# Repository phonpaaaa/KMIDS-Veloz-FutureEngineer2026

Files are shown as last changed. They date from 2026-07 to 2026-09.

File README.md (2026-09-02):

<div align="center">

# KMIDS Veloz
## 2026 WRO – Future Engineers
**Official Engineering Documentation**

> Designing, building, and continuously improving an autonomous vehicle for the World Robot Olympiad Future Engineers challenge.

<!-- IMAGE: Robot overview photo (final robot, 3/4 angle, clean background) -->
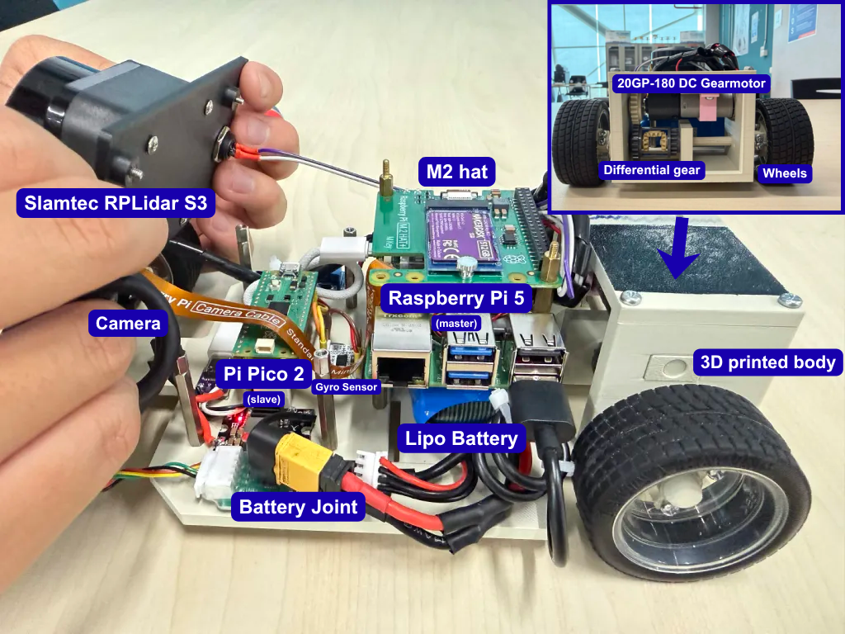
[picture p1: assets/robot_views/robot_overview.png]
Robot overview


</div>

---

## Team Members

<!-- IMAGE: Team photo -->

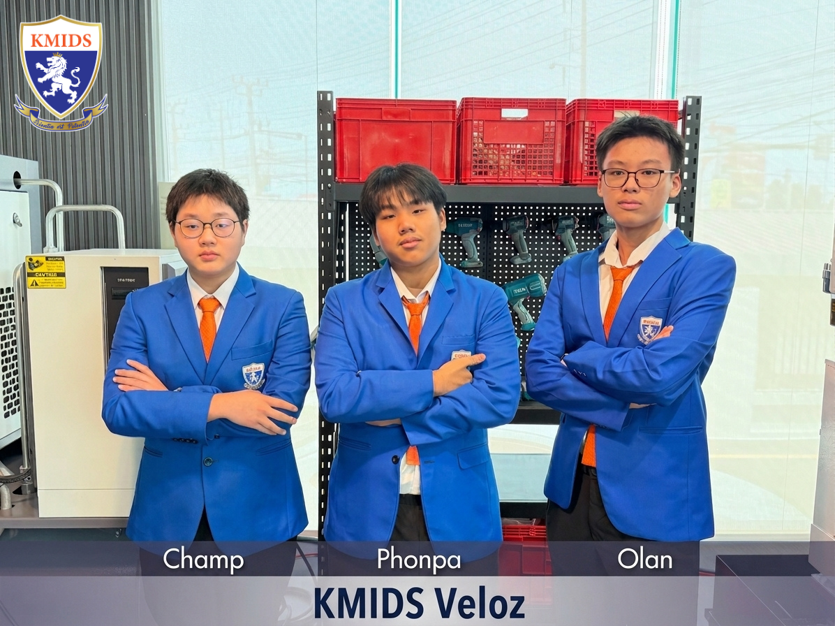
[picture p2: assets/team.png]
Team photo


| Member Name | Chief Responsibilities | Key Activities |
|---|---|---|
| **Sahas Ninvatchararang (Phonpa)** | Robotics, Electronics & Software | Physical robot construction, electronics integration, sensor and motor implementation, programming, control-system development, and testing |
| **Olan Sinsuriya (Olan)** | CAD, Mechanical Design & Engineering | Chassis and component CAD, mechanical design, assembly development, design iterations, and fabrication support |
| **Phisit Chuthomsuwan (Champ)** | Documentation, Research & Project Coordination | Technical documentation, research, recording development decisions, organizing project information, and supporting testing and validation |

During the development process, we divided the work while also supporting each other, meaning one person may focus on designing CAD models, while helping debug the initial calibration code. This was to ensure proper coordination and teamwork.

**KMIDS Veloz** is a team of students exploring autonomous driving through mechanical design, embedded systems, computer vision, and control theory. Over the course of the WRO Future Engineers 2026 season, our work has covered hardware selection, CAD design, electronics integration, and the software architecture running on our two onboard boards (Raspberry Pi 5, Raspberry Pico), along with the testing and iteration that shaped each of those decisions. This document outlines our entire process from start to finish, including engineering decisions, hurdles, and the eventual solutions we found after rigorous trials.

---
## Table of Contents

1. [Overview](#1-overview)
   - [1.1 About the Project](#11-about-the-project)
   - [1.2 Robot Images](#12-robot-images)
   - [1.3 Performance Video](#13-performance-video)
2. [Mobility Management](#2-mobility-management)
   - [2.1 Drive System](#21-drive-system)
   - [2.2 Steering](#22-steering)
   - [2.3 Chassis Design](#23-chassis-design)
3. [Power and Sense Management](#3-power-and-sense-management)
   - [3.1 Power Source](#31-power-source)
   - [3.2 Sensor and Camera](#32-sensor-and-camera)
   - [3.3 Processing Units](#33-processing-units)
   - [3.4 Circuit Diagram](#34-circuit-diagram)
   - [3.5 Power Consumption](#35-power-consumption)
4. [Software Architecture](#4-software-architecture)
   - [4.1 Code Organization](#41-code-organization)
   - [4.2 Sensing Modules](#42-sensing-modules)
   - [4.3 Reactive Navigation Controller](#43-reactive-navigation-controller)
5. [Obstacle Management](#5-obstacle-management)
   - [5.1 Open Challenge](#51-open-challenge)
   - [5.2 Obstacle Challenge](#52-obstacle-challenge)
   - [5.3 Parallel Parking](#53-parallel-parking)
6. [Systems Thinking and Engineering Decisions](#6-systems-thinking-and-engineering-decisions)
7. [Testing and Results](#7-testing-and-results)
8. [Source Code](#8-source-code)
   - [8.1 API Documentation](#81-api-documentation)
   - [8.2 Code Structure](#82-code-structure)
   - [8.3 Compilation / Upload Instructions](#83-compilation--upload-instructions)
9. [List of Components](#9-list-of-components)
10. [3D Model Files](#10-3d-model-files)
    - [10.1 FreeCAD Files](#101-freecad-files)
    - [10.2 STL Files](#102-stl-files)
    - [10.3 Slicer Files](#103-slicer-files)
11. [Building Instructions](#11-building-instructions)
12. [Development Process and Future Improvements](#12-development-process-and-future-improvements)
    - [12.1 Mechanical and Software Iteration History](#121-mechanical-and-software-iteration-history)
    - [12.2 Planned Improvements](#122-planned-improvements)
13. [License](#13-license)

---

## 1. Overview

### 1.1 About the Project

The WRO Future Engineers category requires a vehicle to complete a driving course fully autonomously. The competition is split into two challenges. In the **Open Challenge**, the robot must complete three laps of an empty track without making contact with any wall. In the **Obstacle Challenge**, the track additionally contains randomly placed obstacle pillars that the robot must pass on the correct side, and the run finishes with a precision parallel-parking maneuver into a bay whose position is not known in advance. In both challenges the driving direction and track layout are randomized before the run starts, and in the Obstacle Challenge the pillar placement is randomized too, so the robot has to work out what it's facing from its own sensors rather than following a pre-programmed path.

Our robot splits its computing across two boards, connected over I²C with the Pi 5 as master and the Pico 2 as slave. A **Raspberry Pi 5** handles perception, LIDAR distance sensing and camera-based pillar detection, and runs the navigation logic that decides steering and speed. A **Raspberry Pi Pico 2** takes those commands and drives the motor and steering servo, reporting back encoder and IMU telemetry. Because the Pico is a pure I²C slave, it only acts on the most recent command written to it and does not initiate communication itself (Section 3.3, Section 6).

Our active control software is a hand-tuned reactive LIDAR controller: it reacts directly to the four LIDAR distance readings around the robot rather than planning a path or holding a fixed heading. An earlier version of the codebase used per-axis heading control with an explicit lap/turn state machine; that module (`open_challenge.cpp`) is documented in full in Section 5.1 and Section 12.1. Camera-based pillar detection (`camera.cpp`) is documented in Section 4.2 and Section 5.2. Sections 4, 5, and 12 note the integration status of each piece.

### 1.2 Robot Images

The six required orientation views, four additional angled shots, and a photo of the internal electronics layout are collected below.

<!-- IMAGES: required six views, using our actual filenames -->
| Front | Rear | Left |
|---|---|---|
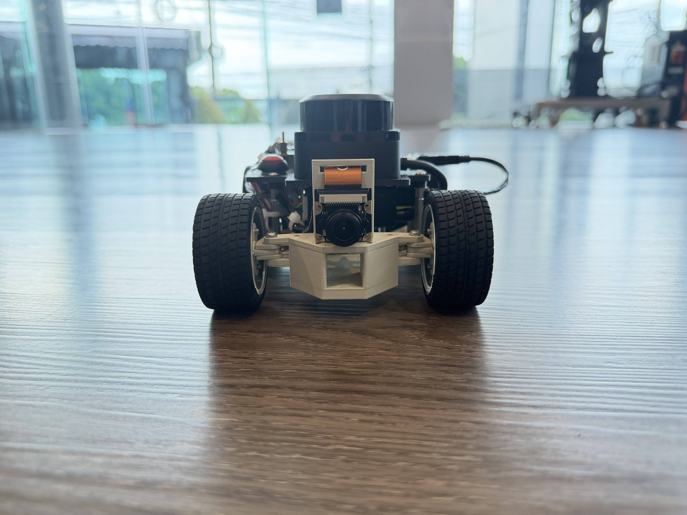
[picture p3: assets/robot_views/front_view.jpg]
Front
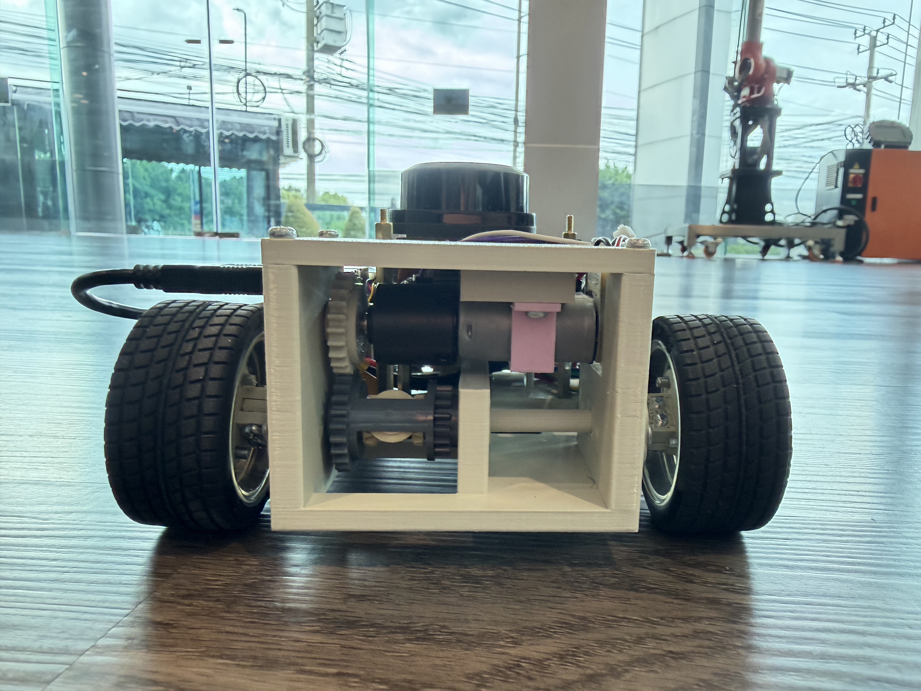
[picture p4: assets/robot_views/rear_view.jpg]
Rear
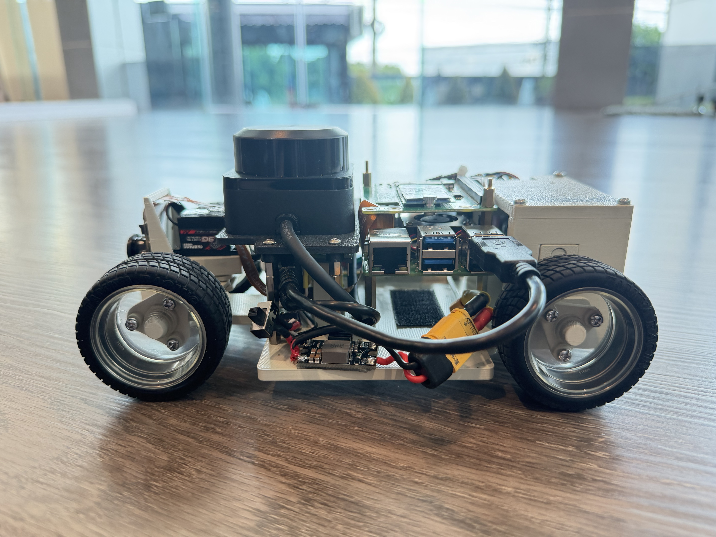
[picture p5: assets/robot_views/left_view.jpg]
Left
|  |  |  |

| Right | Top | Bottom |
|---|---|---|
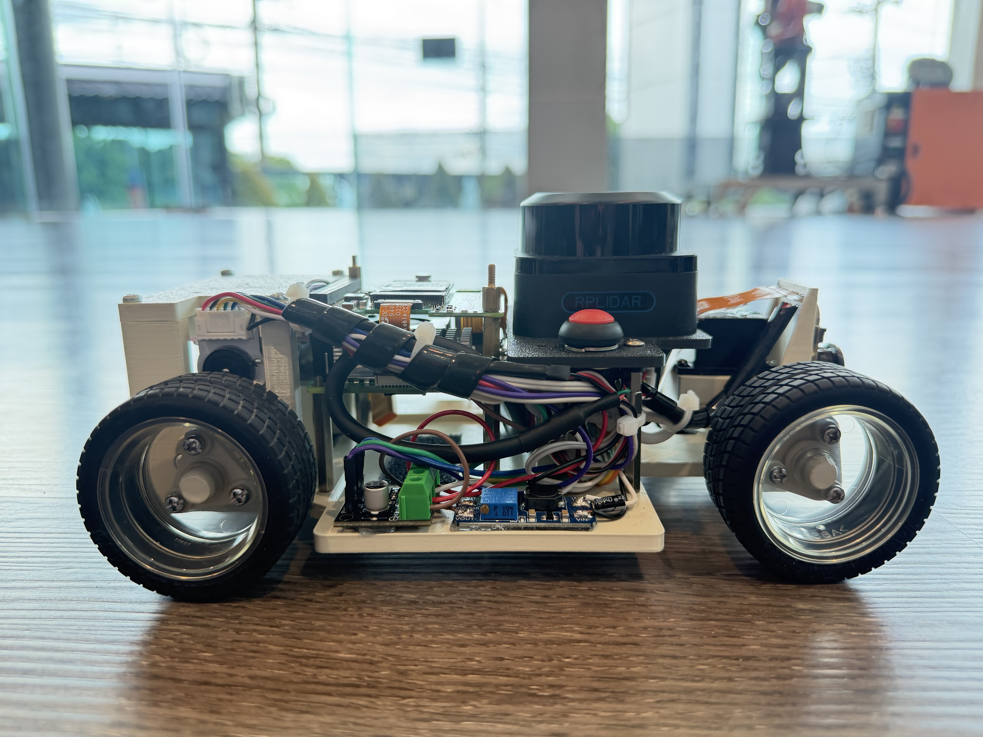
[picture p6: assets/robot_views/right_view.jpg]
Right
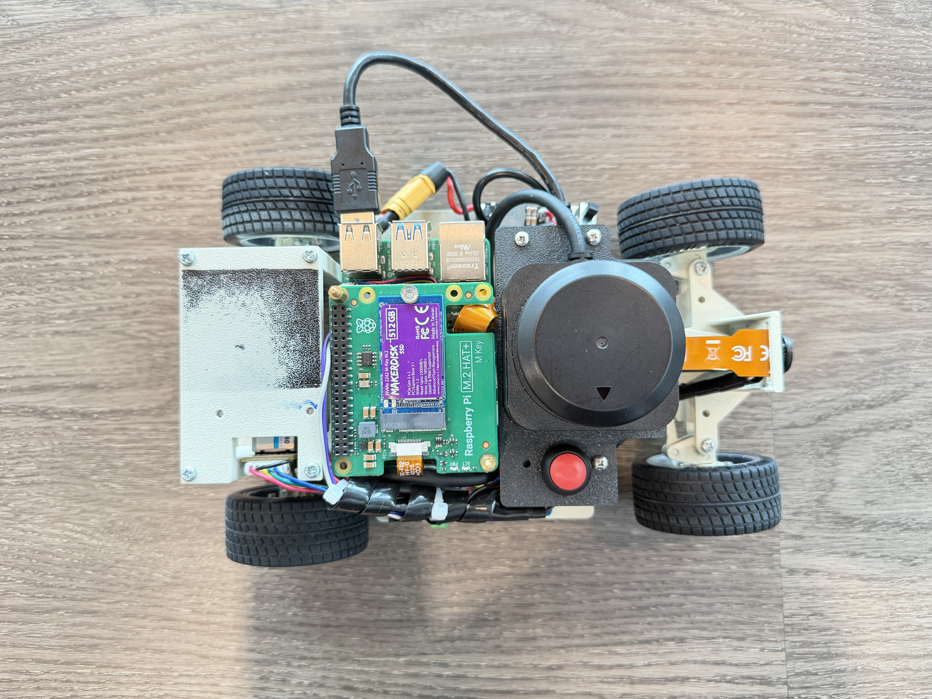
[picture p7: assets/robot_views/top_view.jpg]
Top
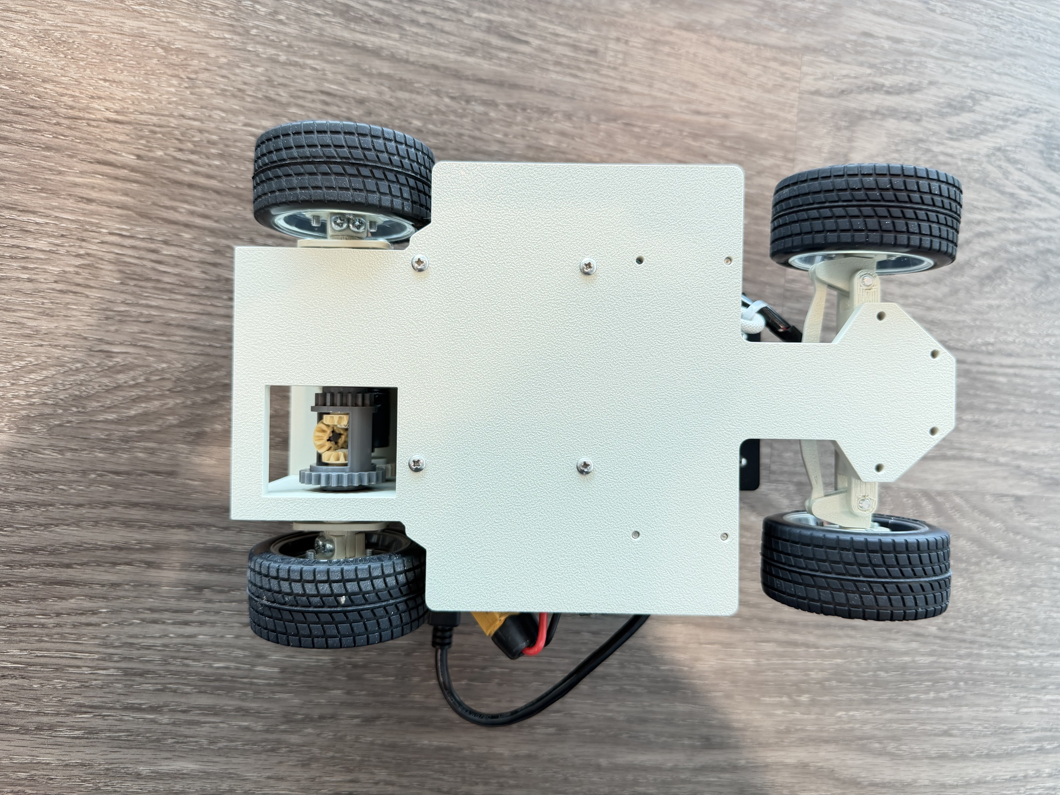
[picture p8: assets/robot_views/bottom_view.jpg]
Bottom
|  |  |  |

**Additional angles:**

| Left side | Left-rear | Right side | Right-rear |
|---|---|---|---|
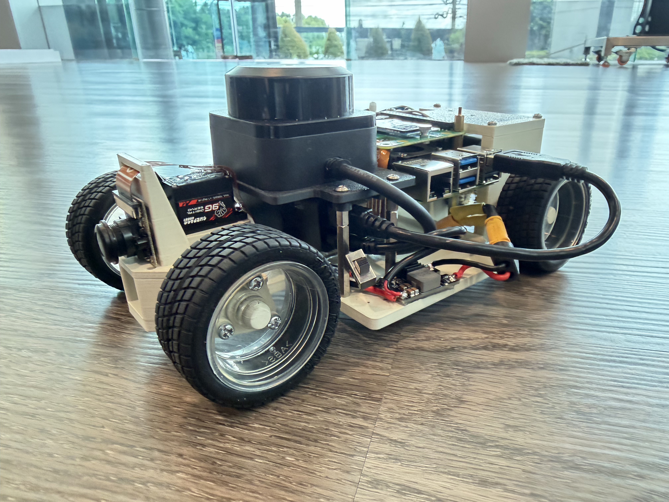
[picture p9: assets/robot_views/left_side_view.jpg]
Left side
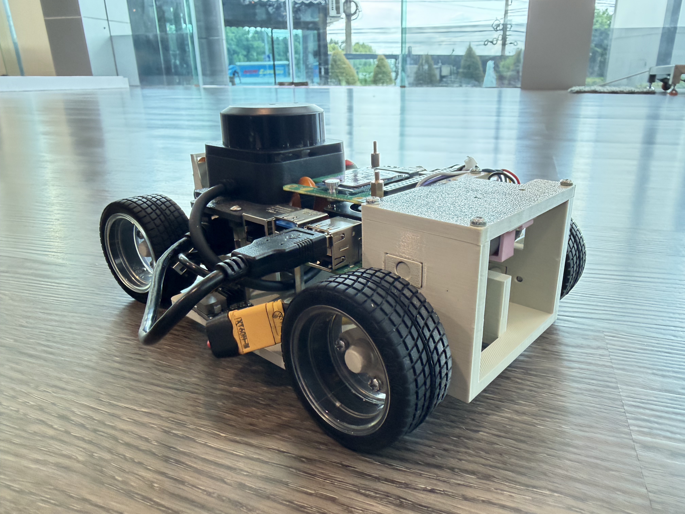
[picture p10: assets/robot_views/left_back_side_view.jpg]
Left rear
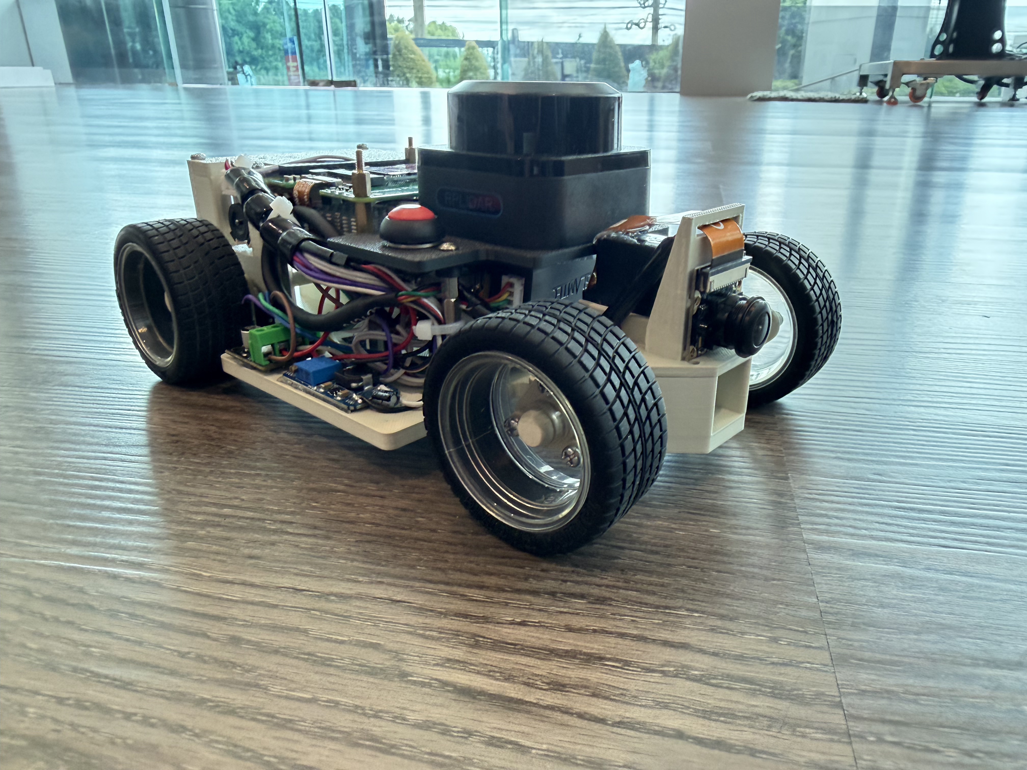
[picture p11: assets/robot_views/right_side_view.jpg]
Right side
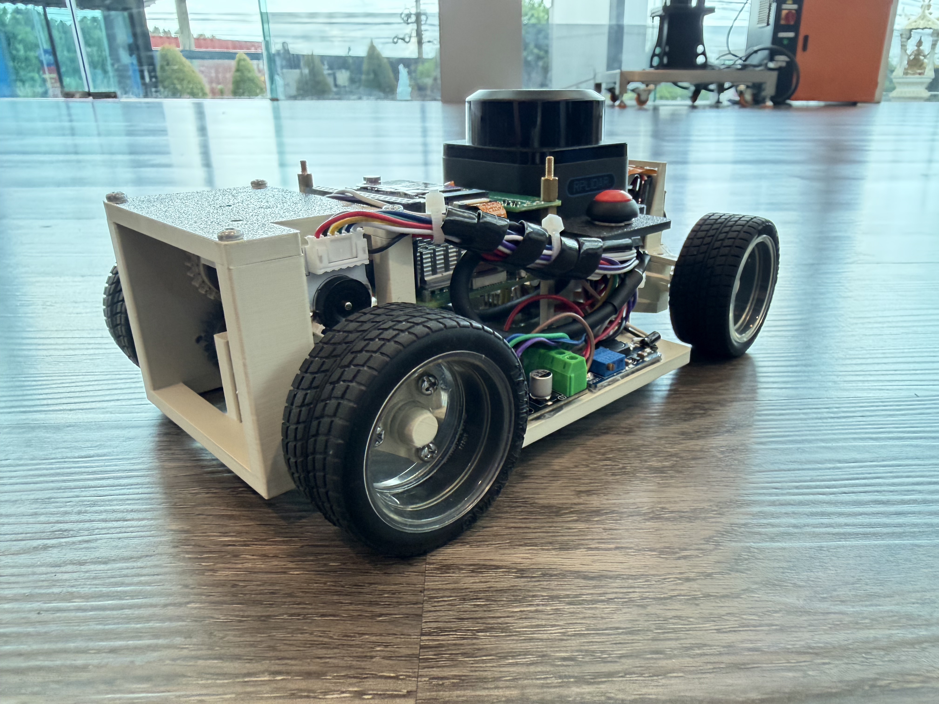
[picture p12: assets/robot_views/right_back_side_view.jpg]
Right rear
|  |  |  |  |

*In the six orientation views and the additional four angled views, the Li-Po battery is not part of the physical assembly, as it was being tested during the photo-taking process.*

**Internal Electronics:**

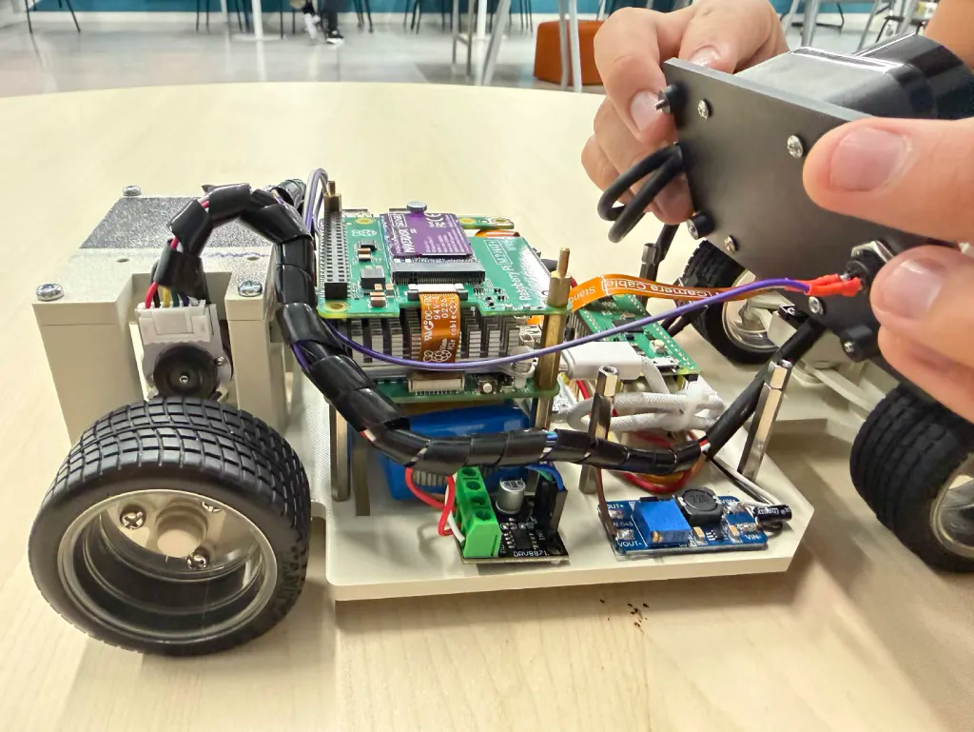
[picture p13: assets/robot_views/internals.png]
Internal electronics


Section 3.2 also includes a labeled top-down sensor placement diagram (`assets/sensor_placement.png`) showing LIDAR, camera, and IMU positions schematically.

### 1.3 Performance Video

**Open Challenge:** *link to be added*

**Obstacle Challenge:** *link to be added*

These two parts show both the Open and Obstacle Challenges respectively.

[Back to Top](#kmids-veloz)

---

## 2. Mobility Management

This section covers how the robot moves: what drives the rear wheels, how the front wheels are steered, and how the chassis is built to hold both systems together.

- **Drive system:** a single 20GP-180 DC gearmotor with an integrated encoder drives the rear wheels through a printed gear.
- **Steering:** the front wheels use Ackermann-geometry steering, actuated by a Surpass Hobby S0009M servo through a printed T-bone/transfer-linkage assembly.

### 2.1 Drive System

The robot uses a single **20GP-180 DC gearmotor with an integrated quadrature encoder** to drive the rear wheels. Power is transferred from the motor through a printed gear system (`MotorGear.FCStd`), while encoder feedback is wired back to the Raspberry Pi Pico 2 so wheel rotation can be measured directly instead of assumed.

<!-- IMAGE: 20GP-180 motor photo -->
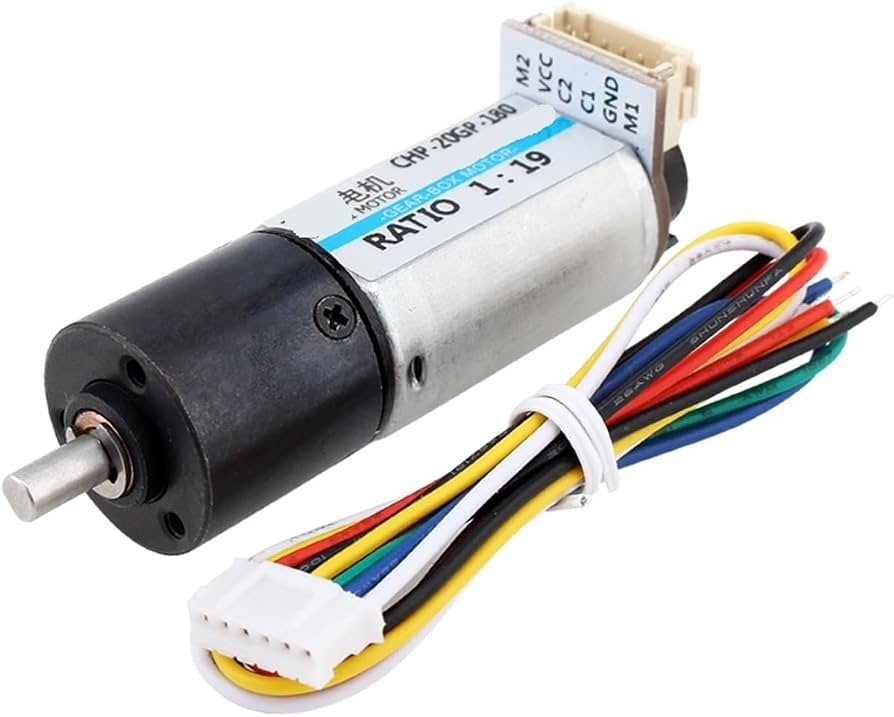
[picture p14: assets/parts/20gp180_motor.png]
20GP-180 DC gearmotor


#### Motor: 20GP-180 DC Gearmotor

The 20GP-180 is the vehicle's only drive motor. It's mounted at the rear of the chassis and drives the rear axle through the printed drivetrain components described below.

**Specifications**

| Specification | Value | Source (evidence) |
|---|---:|---|
| Motor | 20GP-180 DC gearmotor | Manufacturer / vendor documentation |
| Rated voltage | 6–12 V | Manufacturer / vendor documentation |
| Operating voltage | 12 V (stepped up from the 5V logic rail) | Our configuration |
| Weight | ~80 g | Vendor specification |
| Gearbox | All-metal planetary | Vendor specification |
| Encoder | Quadrature (AB dual-phase Hall) | Vendor specification / hardware |
| Encoder pulses | 28 pulses/rev | Our firmware |
| Gear ratio | 100:1 | Our configuration / hardware |
| No-load RPM (this ratio) | ~120–150 RPM at 12V | Vendor family curve |
| Stall torque (this ratio) | ~4–6 kgf·cm at 12V | Vendor family curve |

The 20GP-180 family is sold across several gear ratios with no-load speed and stall torque changing accordingly, so the figures above are read from the vendor's general curve for this ratio rather than a bench measurement of our specific unit. It is possible to put the wheel on a bench and logging encoder counts over a fixed time at full duty to get a real number.

**Reason for selection:** the encoder was the deciding factor in choosing this motor over an equivalent plain DC motor. Encoder feedback means wheel rotation can be measured directly rather than assumed from a PWM duty cycle, which matters because a fixed duty cycle does not produce a fixed speed. The motor's actual output changes as battery voltage, load, and friction change over the course of a run. The 20GP-180 also strikes a useful balance of torque, gearing, and physical size for the current chassis: its geared output provides enough mechanical torque to accelerate the vehicle and hold speed on the competition mat, while its dimensions fit within the rear drivetrain without needing an oversized motor mount.

**Encoder and closed-loop speed control:** the motor's quadrature encoder reports rotational feedback to the Pico 2 as part of its telemetry (`encoder_count`, `rpm_x10` in the `PicoTelemetry` struct, see Section 3.4). At 28 pulses/rev through a 100:1 gear ratio, the encoder gives fine-grained resolution on wheel rotation, over 2,800 counts per output-shaft revolution. The Pi 5's navigation controller currently commands speed open-loop as a percentage (Section 4.3); telemetry is read every loop but is not yet closed into a speed loop on the Pi 5 side. We sequenced it this way on purpose. Tuning a speed controller against steering behavior that was still unstable (Section 7) would mean chasing a moving target, so getting steering solid came first. Closing the loop on `rpm_x10` to hold a literal target wheel speed is next.

**Motor gear:** power from the motor is transferred through a printed motor gear (`MotorGear.FCStd`).

<!-- IMAGE: Motor gear -->
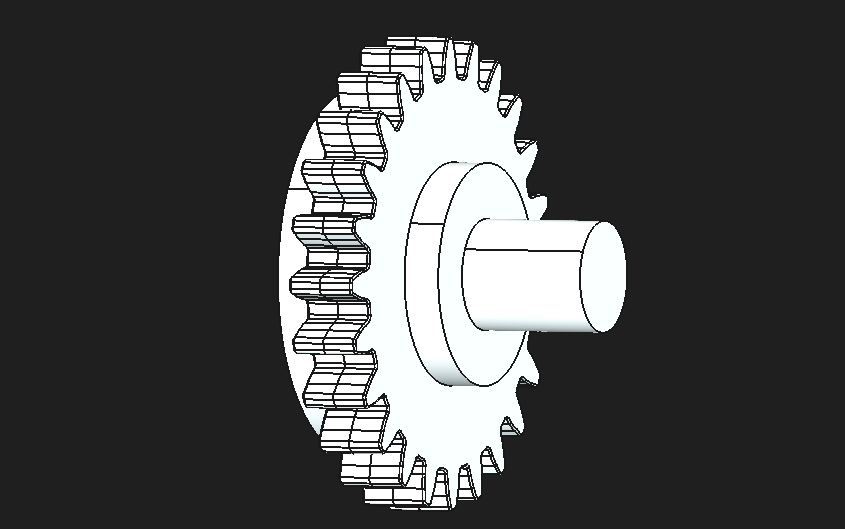
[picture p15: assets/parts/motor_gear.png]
Motor gear


The gear is a separate printed component rather than being integrated directly into the chassis, which makes the drivetrain easier to modify if the motor, gear ratio, or wheel configuration changes during development. Our CAD parts list also includes `LegoBevelGear.FCStd` and `LegoDifferentialGear.FCStd`. We used off-the-shelf LEGO Technic gear elements paired with a `16GA.FCStd` axle rod inside the rear axle assembly rather than designing custom bevel/differential gearing from scratch, which saved print-and-fit iteration on a part that's easy to get wrong and cheap to buy correct.

**Motor mounting:** the motor is mounted using a printed motor holder and a detachable motor plate.

<!-- IMAGE: Motor holder -->
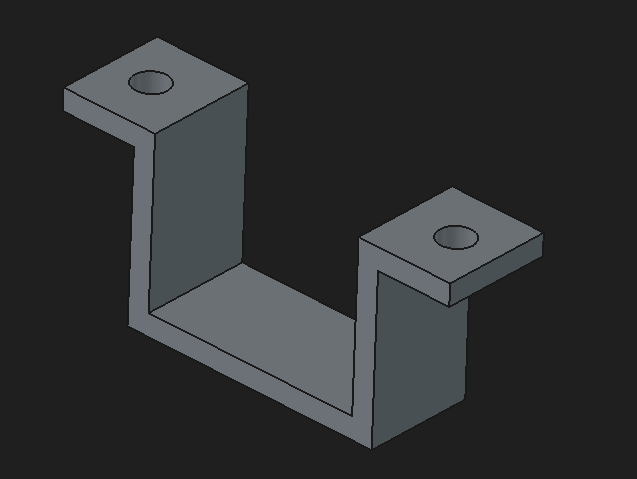
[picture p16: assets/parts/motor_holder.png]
Motor holder


**Motor plate:** the detachable mounting plate that secures the motor holder to the chassis, allowing the motor to be removed or replaced without reprinting the entire chassis.

<!-- IMAGE: Motor plate -->
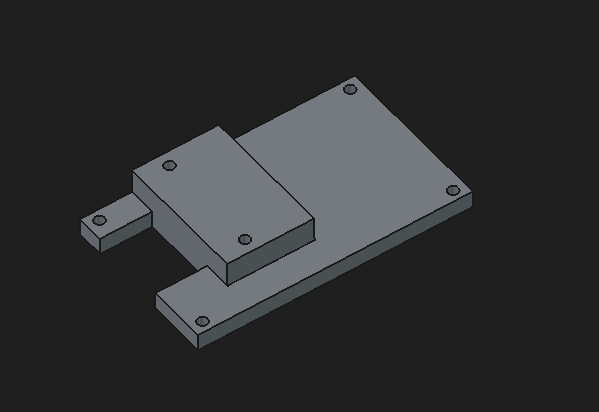
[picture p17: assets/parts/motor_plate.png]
Motor plate


Relevant CAD files: `MotorHolder.FCStd`, `MotorPlate.FCStd`, `MotorGear.FCStd`.

The motor plate is deliberately kept as a separate piece rather than being printed as part of the main chassis. This means the motor can be removed or replaced without requiring the entire chassis to be reprinted, and leaves room for future drivetrain changes. If testing shows a different motor or gear ratio would give better acceleration or top speed, the mounting assembly can be redesigned independently of the main chassis.

**Electrical connection:** the motor is driven by the Raspberry Pi Pico 2 through motor-driver circuitry. The Pico provides PWM/direction control signals rather than powering the motor directly. Encoder signals are wired back to the Pico's encoder inputs, giving it continuous rotation feedback. This keeps the high-current motor path physically separate from the low-voltage control signals:

```text
Raspberry Pi Pico 2
       │  PWM / direction
       ▼
  Motor Driver
       │  motor power
       ▼
  20GP-180 Motor
       │  mechanical output
       ▼
 Rear drivetrain
       │  encoder feedback
       ▼
Raspberry Pi Pico 2
```

**Mechanical integration:** the motor and its mounting components sit at the rear of the chassis so the drivetrain stays contained while leaving the rest of the vehicle available for steering and electronics. Because the motor plate is detachable, the motor can be accessed for maintenance without disassembling the whole chassis.

**Design considerations: torque, speed and integration trade-off:** the main trade-off with the current motor is between speed, torque, size, and how easily it integrates with the rest of the vehicle. At a 100:1 ratio the 20GP-180 gives up top speed in exchange for torque and low-speed control resolution. We picked this ratio deliberately over a lower one (e.g. 30:1–50:1) because the Obstacle Challenge rewards controlled, repeatable maneuvering around pillars and into the parking bay more than raw straight-line speed, and our reactive controller (Section 4.3) already caps speed to 70–73% duty in normal driving. The current ceiling on lap time is cornering confidence, which is a steering/tuning problem (Section 7), not a motor problem. A shorter gear ratio would raise top speed but reduce the torque margin available for accelerating out of corners, and would need a re-tune of the whole reactive controller's speed table.

**Current drivetrain configuration**

| Component | Function |
|---|---|
| 20GP-180 DC gearmotor | Provides drive power |
| Quadrature encoder | Measures rotational movement |
| `MotorGear.FCStd` | Transfers motor output |
| `LegoBevelGear.FCStd` / `LegoDifferentialGear.FCStd` | Off-the-shelf rear axle gearing |
| `16GA.FCStd` | Rear axle rod |
| `MotorHolder.FCStd` | Secures the motor |
| `MotorPlate.FCStd` | Provides detachable motor mounting |
| Motor driver | Controls motor power |
| Raspberry Pi Pico 2 | Sends motor commands, reads encoder telemetry |
| `BackWheelAxleLeft.FCStd` / `BackWheelAxleRight.FCStd` | Transfers rotational movement to wheels |
| `BackWheelConnector.FCStd` | Connects wheels to drivetrain |
| `BackWheelStopper.FCStd` | Secures wheels in place |
| Rear wheels (`Wheel.FCStd`) | Convert motor output into vehicle movement |

#### Motor Selection: Compared Side by Side

Before settling on the 20GP-180, we compared it directly against the two other drive options on the table: a plain (non-encoded) DC gearmotor of similar size, and a continuous-rotation servo, which some teams use to avoid a separate motor driver.

| Option | Speed control | Feedback | Torque | Why we did / didn't pick it |
|---|---|---|---|---|
| 20GP-180 + encoder (chosen) | PWM, closed-loop-ready | Quadrature encoder, 2,800+ counts/rev | 4–6 kgf·cm @12V (100:1) | Only option where wheel speed is measured, not assumed. Directly enables the closed-loop speed control planned in Section 2.1. |
| Plain DC gearmotor (no encoder) | PWM, open-loop only | None | Similar, ratio-dependent | Cheaper and simpler, but duty cycle does not track real speed as battery voltage sags or friction changes. Rejected: no path to closed-loop control without a hardware change later. |
| Continuous-rotation servo | PWM (servo protocol) | None (most hobby-grade units) | Lower, geared for low current draw | Simplifies wiring (no separate motor driver), but has less torque margin for cornering acceleration and no rotation feedback. Rejected: torque and feedback both mattered more than wiring simplicity here. |

### 2.2 Steering

<!-- IMAGE: Ackermann steering geometry reference diagram -->
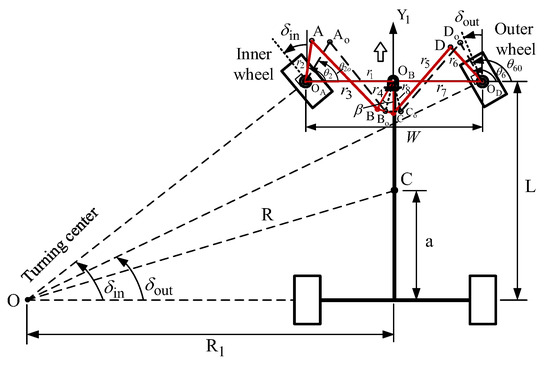
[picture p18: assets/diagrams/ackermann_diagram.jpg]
Ackermann steering geometry


Our steering geometry (`FreeCAD-Files/Models/SteeringAckermannModel.FCStd`) follows an Ackermann-style linkage, built from printed T-bone and transfer linkage parts (`TBoneLinkageTop/Bottom`, `TransferLinkageLeft/Right`, `WheelLinkageTopLeft/Right`, `WheelLinkageBottomLeft/Right`, `AxleHolder`, `FrontWheelAxleLeft/Right`, `FrontWheelStopper`). Ackermann geometry angles the inner and outer front wheels differently during a turn so that both wheels roll instead of scrubbing sideways against the mat. This matters most in the Obstacle Challenge, where the robot needs a tight and repeatable turning radius to get around pillars and into the parking bay without excess slip changing its actual path from run to run.

The diagram above is a general technical reference for the Ackermann geometry principle, not a rendering of our specific linkage. See the FreeCAD file and the CAD assembly image in Section 2.3 for our actual implementation.

#### Servo: Surpass Hobby S0009M (9g digital)

<!-- IMAGE: Servo photo -->
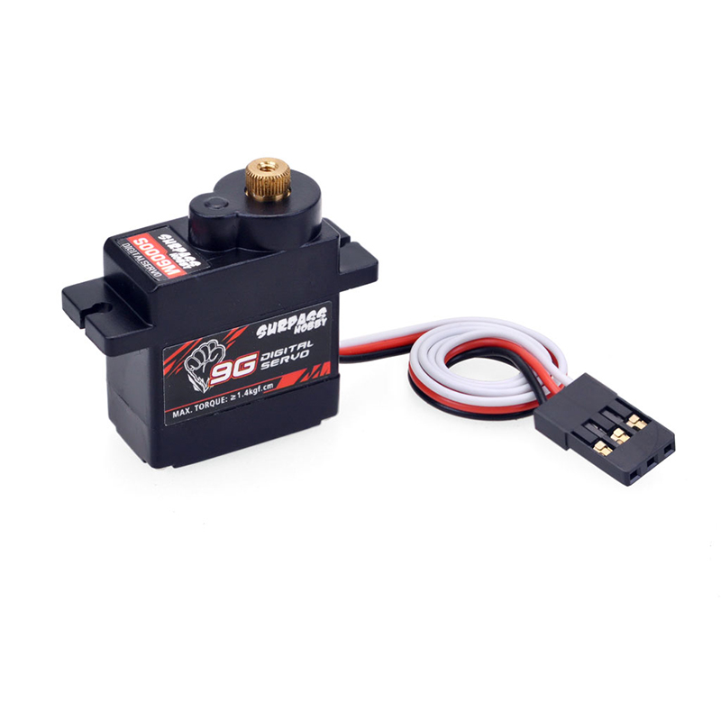
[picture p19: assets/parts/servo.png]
Surpass Hobby S0009M servo


**Specifications**

| Specification | Value | Source |
|---|---|---|
| Rated torque | 1.1 kgf·cm | Vendor specification |
| Speed | 0.15 sec/60° | Vendor specification |
| Voltage | 5V | Vendor specification / hardware |
| Gearing | Metal | Vendor specification / hardware |
| Type | Digital | Vendor specification |

The listed specifications are based on the vendor specification and cross-checked against a second product listing.

**Reason for selection:** the servo's small size and standard PWM interface make it easy to drive directly from the Pico 2, without needing a separate driver board. It also provides enough torque to steer the front wheels responsively at this vehicle's weight, while being small and light enough to mount directly to the front plate without any extra bracketry.

#### Servo Selection: Compared Side by Side

| Option | Torque | Speed | Resolution | Why we did / didn't pick it | Source |
|---|---|---|---|---|---|
| S0009M digital (chosen) | 1.1 kgf·cm | 0.15s/60° | Standard digital PWM | Enough torque for this vehicle's weight, small enough to mount on the front plate directly, and drives natively from the Pico's PWM, no extra driver board needed. | Vendor specification |
| Generic analog 9g servo | ~1.0 kgf·cm | ~0.12–0.20s/60° | Coarser, more deadband | Cheaper, but analog servos have a wider deadband, which showed up as looser centering during early bench tests. Rejected for the tighter steering precision parking demands. | Generic category; not a specific product |
| Larger metal-gear servo (e.g. MG90S-class or bigger) | 2–3 kgf·cm | Similar or slower | Similar digital resolution | More torque margin, but heavier and physically larger than the front plate mount was designed for. Rejected for this chassis revision; noted as the first upgrade path if servo precision becomes a limiting factor (see Design Considerations). | Generic category; not a specific product |

#### Linkages

<!-- IMAGE: T-bone and transfer linkage parts -->
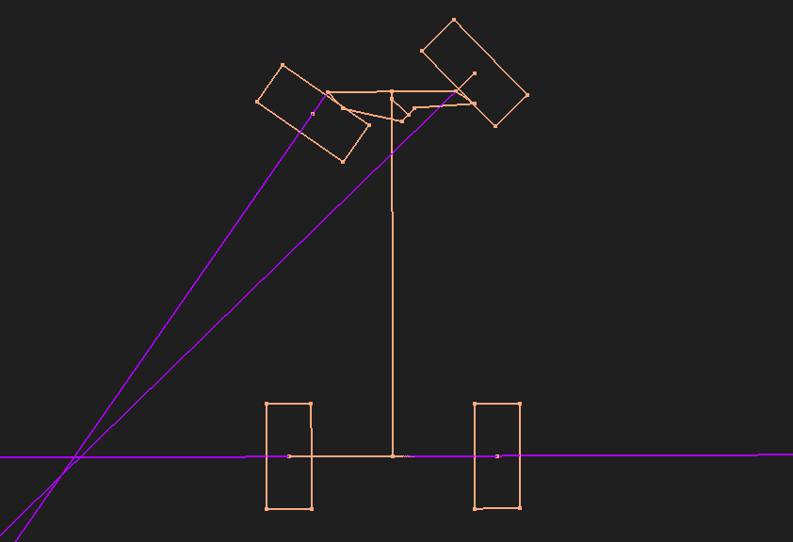
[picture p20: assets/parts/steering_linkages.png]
Steering linkage parts


The T-bone linkage connects the servo horn to the two transfer linkages, which in turn connect to the wheel linkages at each front wheel. Splitting the linkage into separate printed parts (rather than one solid arm) lets us adjust pivot points and re-print a single part if a specific linkage geometry needs revising, instead of reprinting the whole steering assembly.

#### Servo Control

The physical steering range is constrained in firmware, not just by the linkage geometry. Our active navigation controller (`navigation.cpp`, Section 4.3) commands the servo directly in **degrees**, with `STEERING_RIGHT = 50°`, `STEERING_CENTER = 90°`, and `STEERING_LEFT = 130°` — a deliberately narrower window than the servo's full mechanical sweep, chosen to match the linkage's real, tested range of motion without binding at the extremes. The `open_challenge.cpp` module (Section 5.1) uses a slightly narrower range (`60°`–`90°`–`120°`) from an earlier tuning pass. The steering ranges will be reconciled before `open_challenge.cpp` is reactivated.

#### Mounting

<!-- IMAGE: Servo mounting on front plate -->
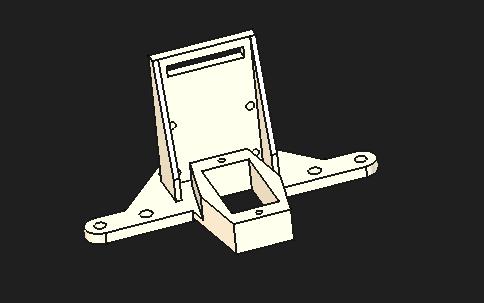
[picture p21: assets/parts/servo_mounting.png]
Servo mounting


The servo is screwed directly into a platform plate at the front of the chassis, connected to the steering mechanism described above.

#### Design Considerations

The S0009M is adequate for the current vehicle weight and turning demands, but a higher-resolution digital servo with a narrower deadband would allow finer steering adjustments, particularly useful for the tight maneuvering required during parking. Driving the servo through a dedicated PWM driver (e.g. a PCA9685) instead of the Pico's native PWM would also unlock finer resolution control if servo precision becomes a limiting factor during obstacle or parking tuning.

Physical steering iterations are validated through the testing results in Section 7.

### 2.3 Chassis Design

The finished chassis body measures 209 mm (long axis) × 130 mm (short axis) × 59 mm (height), measured directly from the FreeCAD model.

| Dimension | Value | Source |
|---|---|---|
| Chassis (L × W × H) | 209 × 130 × 59 mm | Measured from CAD |
| Wheelbase (front-to-rear axle) | 181 mm | Measured from CAD |
| Track width (left-to-right wheel) | 85 mm | Measured from CAD |
| Wheel diameter | 54.7 mm | Measured from CAD |

<!-- IMAGE: Annotated CAD assembly (full robot, labeled: chassis, steering, motor, electronics stack) -->
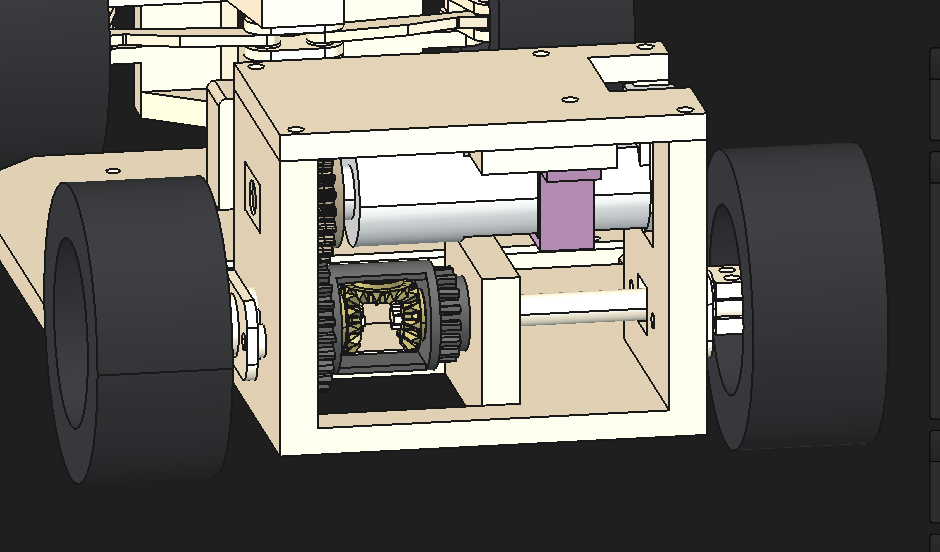
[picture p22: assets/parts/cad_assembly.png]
Annotated CAD assembly


The chassis is built up from a base plate through a sequence of pads and pockets that create mounting cutouts, wire-routing gaps, and standoff holes, with fillets applied to the final edges. This approach does two things at once: it keeps the whole robot well within the WRO 300×200×300mm size limit with margin to spare, and it leaves room to reposition the electronics stack later without having to redesign the body from scratch.

**Design considerations:** the chassis was built with modularity as a priority over minimizing part count. The motor plate, steering front plate, and LIDAR mount are all separate detachable pieces rather than a single printed body, specifically so a subsystem redesign doesn't force a full chassis reprint. A `FrontCover.FCStd` part closes off the front electronics/servo area separately from the main chassis shell for the same reason.

The CAD files for the servo and LIDAR mount are named `S0009M_Mount.FCStd` and `RPLidarS3_Mount.FCStd`, matching the parts installed on the current robot.

[Back to Top](#kmids-veloz)

---

## 3. Power and Sense Management

### 3.1 Power Source

The system's primary logic rail, which supplies the Raspberry Pi 5, Pico 2, camera, IMU, and LIDAR, runs at **5V**. This rail is fed through a UPS module that reports its state of charge over I²C, using register 0x17, matching the EP-0136 protocol implemented in our check_battery_status.py script. This register assignment is based on the module documentation and was cross-checked against an independent reference. Motor power is handled separately: it is stepped up to 12V, since the 20GP-180 gearmotor is rated above what the 5V logic rail can supply on its own.

To protect the battery from being damaged by over-discharge, a `set_battery_min.py` / `ups_shutdown.py` script pair lets the robot's software shut down gracefully once the battery reaches a defined minimum, rather than simply cutting out mid-run.

**Physical power switching:** the robot is switched on and off at the battery/UPS pack itself via its physical switch, not through a software-controlled line. The Raspberry Pi OS shutdown sequence (`ups_shutdown.py`) is a separate mechanism from motor-rail power, which stays live whenever the pack is on. The only software-side stop mechanism right now is the `emergency_stop` flag in `PicoCommand` being honored by the Pico firmware. There's no relay or MOSFET gating the 12V motor rail independently. A physical, easily reachable kill switch on the battery pack is standard practice at competition regardless of what the software does.

### 3.2 Sensor and Camera

<!-- IMAGE: Sensor placement photo/diagram: top-down or side view showing lidar/camera/IMU mounting points -->
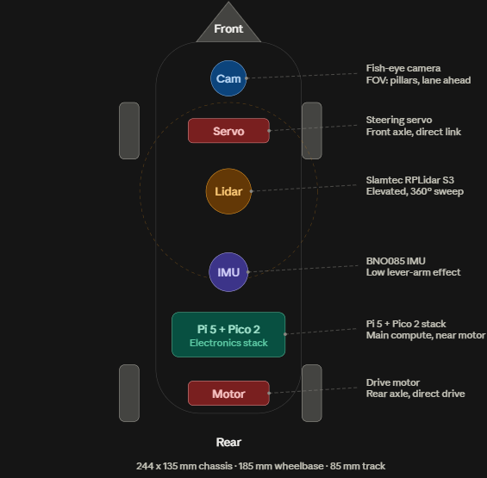
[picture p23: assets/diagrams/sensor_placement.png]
Sensor placement


Each sensor's mounting position was chosen for a specific reason tied to what it needs to see or measure, rather than wherever happened to have free space on the chassis.

| Sensor | Placement | Why there |
|---|---|---|
| Slamtec RPLidar S3 | Front, elevated above the camera/servo stack on a standoff-mounted plate | 360° unobstructed view needs it clear of the chassis body and steering linkage below it |
| Fish-eye camera | Front plate, forward-facing | Needs a forward view of pillars and lane lines ahead of the robot; front-mounting keeps its field of view unobstructed by the chassis |
| BNO085 IMU | Center of chassis, near the Pico 2 | Mounting near the physical center of rotation reduces the lever-arm effect of vibration and centripetal acceleration during turns, which otherwise pollutes the accelerometer/gyro reading |

**Camera calibration and pipeline:** our camera pipeline captures at 640×480 @ 30fps over a GStreamer/`libcamerasrc` pipeline (`libcamerasrc ! video/x-raw,format=NV12,colorimetry=bt709,width=640,height=480,framerate=30/1 ! queue ! videoconvert ! video/x-raw,format=BGR ! appsink drop=true max-buffers=1 sync=false`). The `drop=true max-buffers=1 sync=false` appsink configuration always hands the processing loop the newest available frame and discards anything older, rather than letting frames queue up if a loop iteration runs slow. For a reactive controller, a stale frame is worse than a dropped one. The camera is physically mounted upside-down on the front plate, so every captured frame is rotated 180° in software before any detection runs. Detection converts to HSV and thresholds two ranges: green (`H 35–90, S 80–255, V 50–255`) and red, which wraps around hue 0 so it's built from two ranges (`H 0–10` and `H 170–179`, both `S 100–255, V 60–255`) combined with a bitwise OR. Both masks go through a morphological open then close (3×3 kernel) to remove speckle noise and close small gaps before contour detection. Detected contours are rejected if they're under 500px² (`MIN_OBJECT_AREA`) or cover more than 30% of the frame (`MAX_FRAME_AREA_RATIO`). A further shape filter requires `height > width * 1.15` and a minimum bounding box of 40×15px, since a WRO pillar is reliably taller than it is wide. Exposure and white balance are locked for consistent detection.

<!-- IMAGE: Camera detection pipeline -->
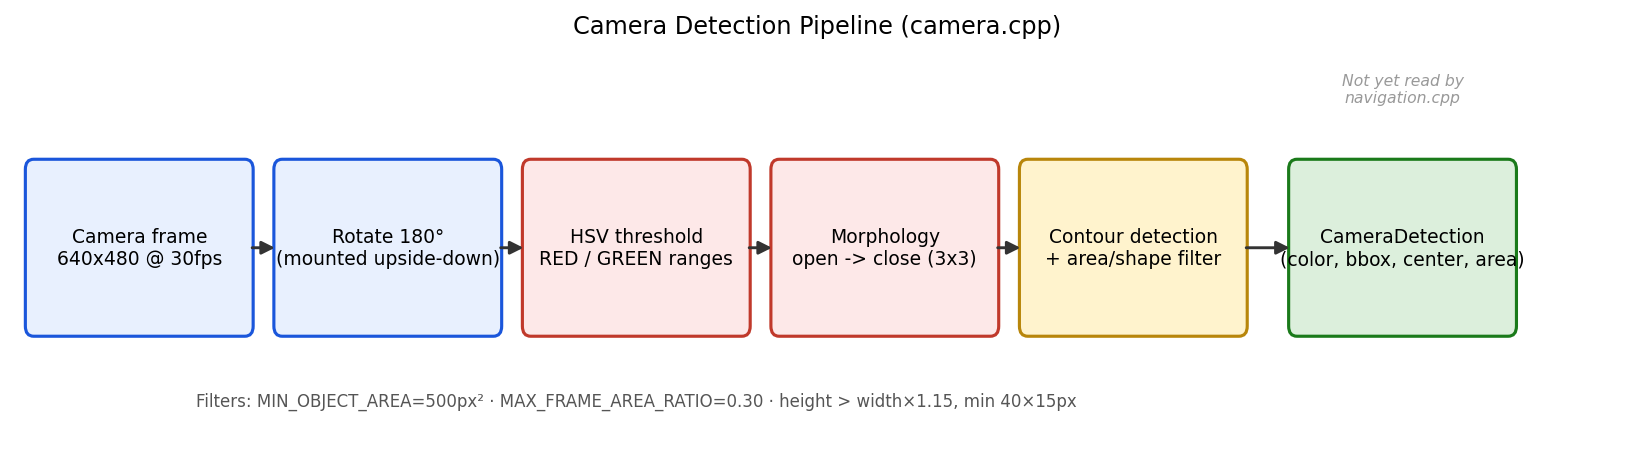
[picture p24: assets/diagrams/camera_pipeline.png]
Camera detection pipeline


**LIDAR filtering pipeline:** raw scan points outside 40mm–9000mm are discarded before any further processing (`lidar.cpp`). Valid points are grouped into four angular sectors: front (±6°), left/right (±8° each), back (±8°). Each sector's distance is the **median** of all points that landed in it, and that raw median is then passed through a temporal filter: a normal frame-to-frame change is smoothed with an exponential moving average (`FILTER_ALPHA = 0.40`), but a jump larger than 1200mm is only accepted once it's been seen for 3 consecutive frames (`JUMP_CONFIRM_FRAMES`). This stops a single bad LIDAR return from producing a one-frame phantom wall or opening. The navigation controller (Section 4.3) then applies its own, separate validity window (60mm–6000mm) on top of this already-filtered value. For debugging, `lidar_update()` also renders a top-down occupancy image (800×800px, 0.08 px/mm) with the raw point cloud, Hough-transform-detected wall line segments, and range rings, saved to disk every scan, very useful for bench tuning.

<!-- IMAGE: LIDAR angular sector diagram -->
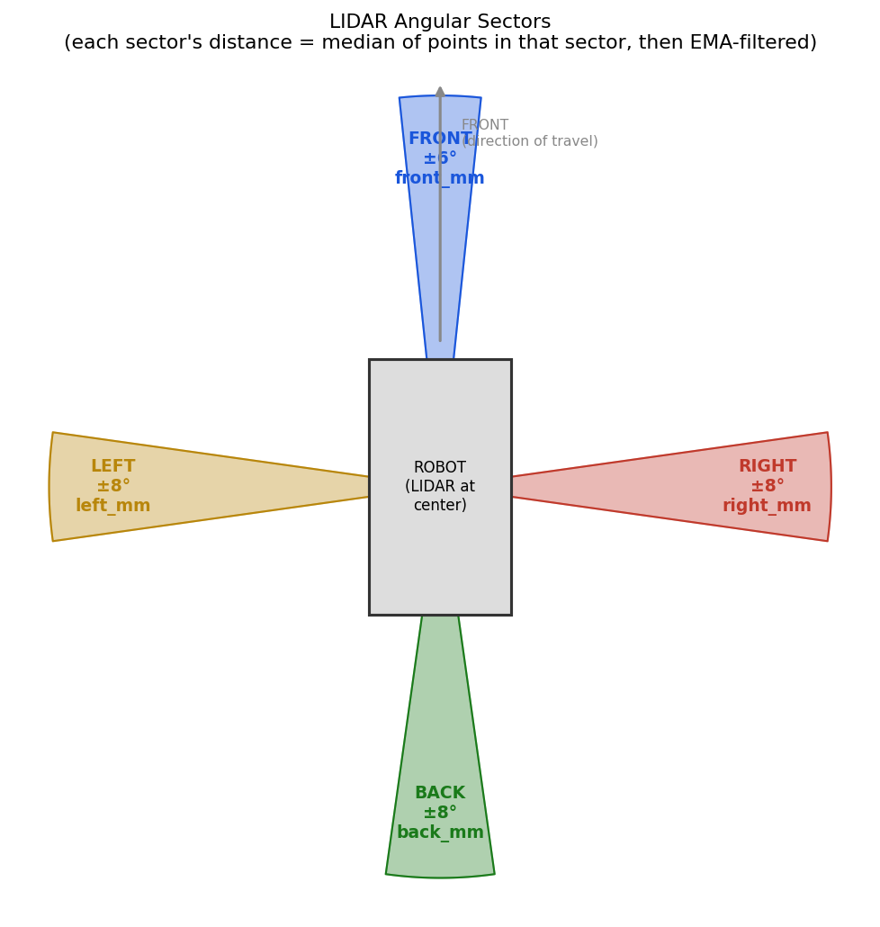
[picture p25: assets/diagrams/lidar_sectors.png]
LIDAR angular sectors


The diagram above shows the four angular sectors (front ±6°, left/right ±8°, back ±8°) the raw point cloud is grouped into before the median + EMA filtering described above is applied, narrower sectors than an earlier ±15° version, specifically to keep an adjacent wall or opening from bleeding into the wrong sector's reading.

#### LIDAR Selection: Compared Side by Side

We evaluated several LIDAR options over the season before settling on the RPLidar S3. Our original unit had ranges and angular resolution that were hard to work with reliably at our update rate, so we compared it directly against the S3 and against a cheaper alternative:

| Option | Range (dark/low-reflectivity) | Sample rate | Angular resolution | Why we did / didn't pick it | Source |
|---|---|---|---|---|---|
| RPLidar S3 (chosen) | Up to 15 m at 10% reflectivity | 32,000 samples/sec | 0.1125° | Better low-reflectivity range and a smaller, lighter housing than our previous unit, while keeping the same UART interface and mounting pattern our chassis was already designed around. | Vendor specification |
| RPLidar C1 (previous) | Up to 6 m at 10% reflectivity | 5,000 samples/sec | 0.72° | Functional in early testing, but we found it wasn't sufficient for running the robot well. The range and resolution were both very hard to work with at our sector-median update rate. | Vendor specification |
| RPLidar A1 | Up to 6 m typical, shorter effective range indoors | ~8,000 samples/sec | ~1° (lower resolution) | Cheaper and widely documented, but the coarser angular resolution and lower sample rate give noisier sector medians at our update rate. Rejected for this build. | Vendor specification |

The listed specifications are based on manufacturer specifications; the S3 specifications were cross-checked against an independent listing.

**Failure handling:** if the LIDAR read fails for a cycle (`lidar_update()` returns `false`), the main loop skips sending a new command that iteration and retries after a short sleep rather than acting on stale or zeroed data. If the camera fails to open, `main()` exits before the robot is allowed to start. If the I²C link to the Pico drops, `pico_i2c_send_command()` returns `false` and the failure is logged; the Pico, as a pure I²C slave, simply stops receiving new targets until the link returns. The I²C link includes retry logic on the Pi 5 side and a watchdog timer on the Pico 2.

### 3.3 Processing Units

| Board | Role | Responsibility |
|---|---|---|
| Raspberry Pi 5 | I²C master | LIDAR distance sensing, camera pillar detection, reactive navigation decision-making |
| Raspberry Pi Pico 2 | I²C slave (address `0x39`) | Executes motor/steering commands, reports encoder + IMU telemetry |

<!-- IMAGE: Pi 5 / Pico 2 I2C master-slave relationship -->
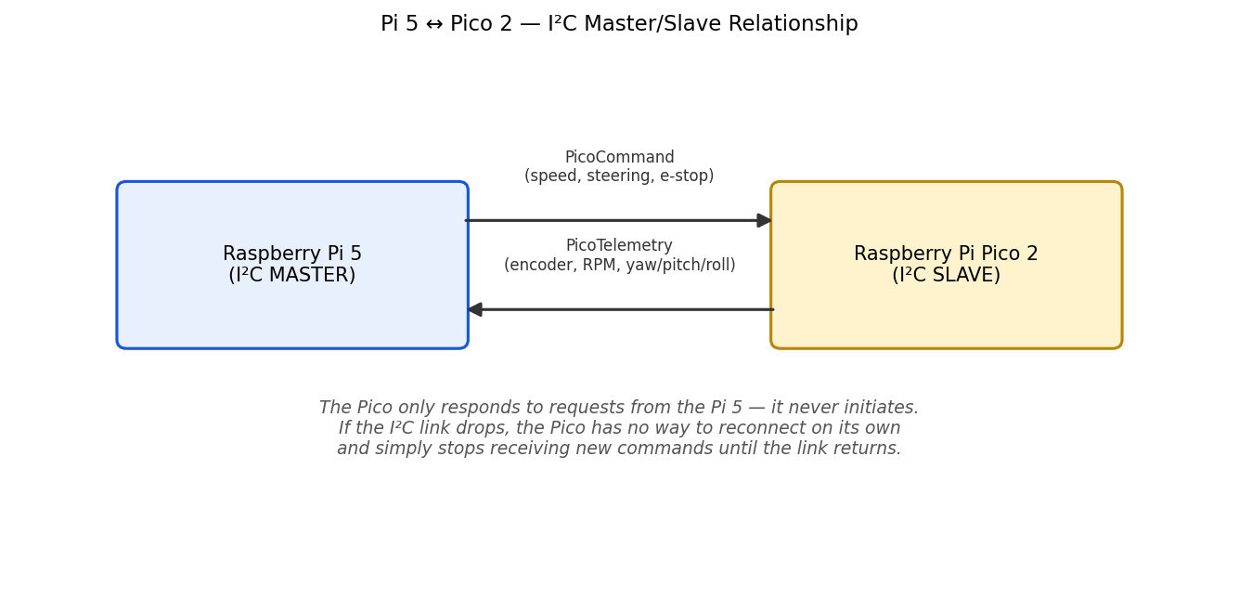
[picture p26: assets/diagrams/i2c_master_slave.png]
I2C master/slave relationship


The Pi 5 handles sensing and decision-making because that workload isn't hard-real-time; it can tolerate an occasional slow frame without breaking anything downstream. Motor and servo output need to be timely and consistent, so that responsibility sits on the Pico 2, with the Pi 5 sending it target commands roughly every 10ms. Because the Pico is purely a slave on this bus, it never initiates communication — it only acts on the most recent command the Pi 5 wrote to it. Section 4 covers the current software split in detail.

### 3.4 Circuit Diagram

<!-- IMAGE: Wiring/power block diagram -->
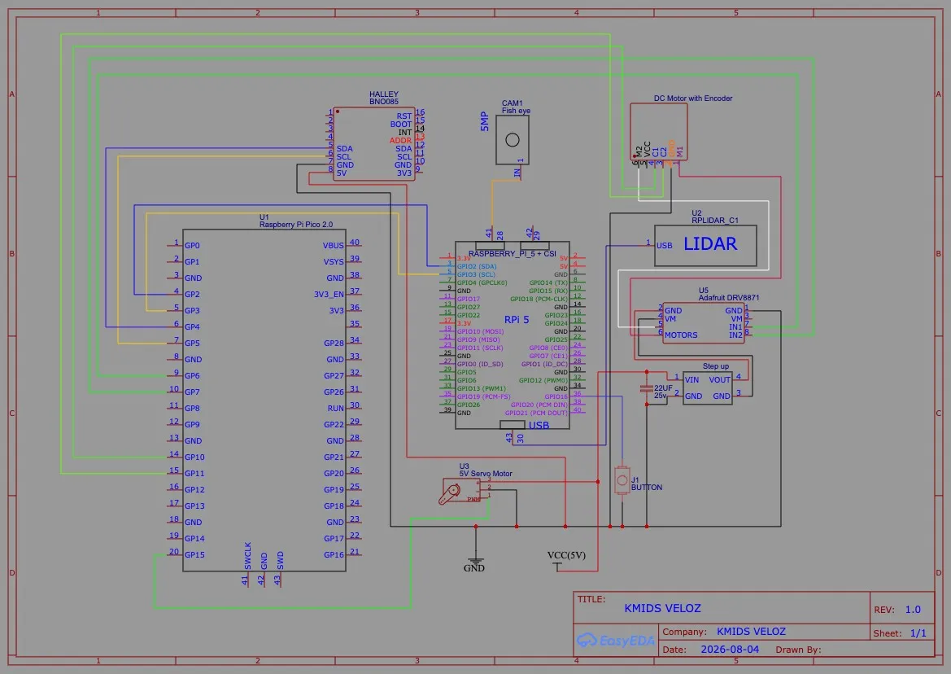
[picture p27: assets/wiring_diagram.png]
Wiring diagram


The Pi 5 and Pico 2 communicate over I²C at address `0x39`. Commands are sent as three raw bytes: speed percent, steering angle, and an emergency-stop flag, packed directly from a `PicoCommand` struct; telemetry is read back as a fixed-size byte block and reinterpreted directly as a `PicoTelemetry` struct via `memcpy`:

```cpp
struct PicoCommand {
    int8_t  speed_percent;    // -100..100
    uint8_t steering_angle;   // 50 (right) .. 90 (center) .. 130 (left), degrees
    uint8_t emergency_stop;   // 1 = stop immediately
};

struct PicoTelemetry {
    int32_t encoder_count;
    int16_t rpm_x10;          // motor RPM x 10 (fixed-point)
    int16_t yaw_x10;          // IMU yaw x 10
    int16_t pitch_x10;
    int16_t roll_x10;
};
```

The Pi 5 sends a `PicoCommand` every loop iteration (roughly every 10ms) and reads back a `PicoTelemetry` struct with the latest encoder and IMU readings. This is a simpler protocol than a shared-memory address map. It trades some flexibility for being easier to reason about and debug. One thing worth flagging: reading `PicoTelemetry` via raw `memcpy` assumes identical struct packing/alignment between the Pi 5 (ARM Cortex-A76) and Pico 2 (RP2350) toolchains, which hasn't been formally verified. It works today, but a future struct or compiler change on either side could silently corrupt telemetry. Explicit fixed-layout serialization is the planned mitigation (see Section 6), not yet implemented.

### 3.5 Power Consumption

The system uses a dual-voltage topology: a main 5V logic rail supplied via the I²C-monitored UPS module, and a stepped-up 12V rail dedicated to the drive motor to isolate high-current inductive spikes from logic electronics.

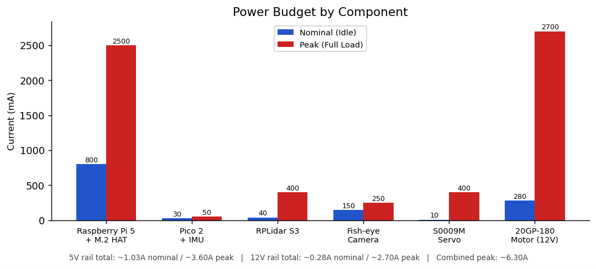
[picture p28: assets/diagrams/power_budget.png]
Power budget by component


| Component | Rail Voltage | Nominal Current (Idle) | Peak Current (Full Load) | Notes / Source |
|---|---|---|---|---|
| **Raspberry Pi 5 (8 GB) + M.2 HAT** | 5V | ~800 mA | ~2,500 mA | Estimated from manufacturer power specifications and our configuration |
| **Raspberry Pi Pico 2 + IMU (BNO085)** | 5V | ~30 mA | ~50 mA | Estimated from component specifications and our configuration |
| **Slamtec RPLidar S3** | 5V | ~40 mA | ~400 mA | Manufacturer specification / operating configuration |
| **Fish-eye Camera (5MP)** | 5V | ~150 mA | ~250 mA | Manufacturer specification / operating configuration |
| **Surpass Hobby S0009M Servo** | 5V | ~10 mA | ~400 mA | Manufacturer specification / estimated operating peak |
| **20GP-180 DC Gearmotor** | 12V (boosted) | ~280 mA | ~2,700 mA | Vendor specification / measured operating behavior |

**Power Budget Summary**

- **5V Logic Rail Total:** ~1.03 A (Nominal) / **~3.60 A (Peak)**
- **12V Motor Rail Total:** ~0.28 A (Nominal) / **~2.70 A (Peak)**
- **Combined system peak:** ~6.30 A across both rails simultaneously

[Back to Top](#kmids-veloz)

---

## 4. Software Architecture

### 4.1 Code Organization

The active Raspberry Pi 5 codebase (project `RaspberryPi5Controller`, built executable `rpi5_controller`) is organized as a flat set of modules under `src/`/`include/` rather than a deeper `modules/processors/utils` hierarchy:

| File | Role |
|---|---|
| `camera.cpp` / `camera.h` | Captures frames and detects red/green pillar candidates |
| `lidar.cpp` / `lidar.h` | Reads the RPLidar S3 and reduces a full scan to four filtered directional distances |
| `navigation.cpp` / `navigation.h` | The active reactive controller, turns LIDAR distances into steering/speed commands |
| `open_challenge.cpp` / `open_challenge.h` | A heading-hold state machine for lap/turn tracking (Section 5.1) |
| `pico_i2c.cpp` / `pico_i2c.h` | Sends `PicoCommand`s to and reads `PicoTelemetry` from the Pico 2 |
| `start_button.cpp` / `start_button.h` | Reads the physical start button (GPIO 16, libgpiod v2, active-low with a 30ms hardware debounce) |
| `main.cpp` | Wires the above together into the main loop |

<!-- IMAGE: Pi 5 software module / data-flow diagram -->
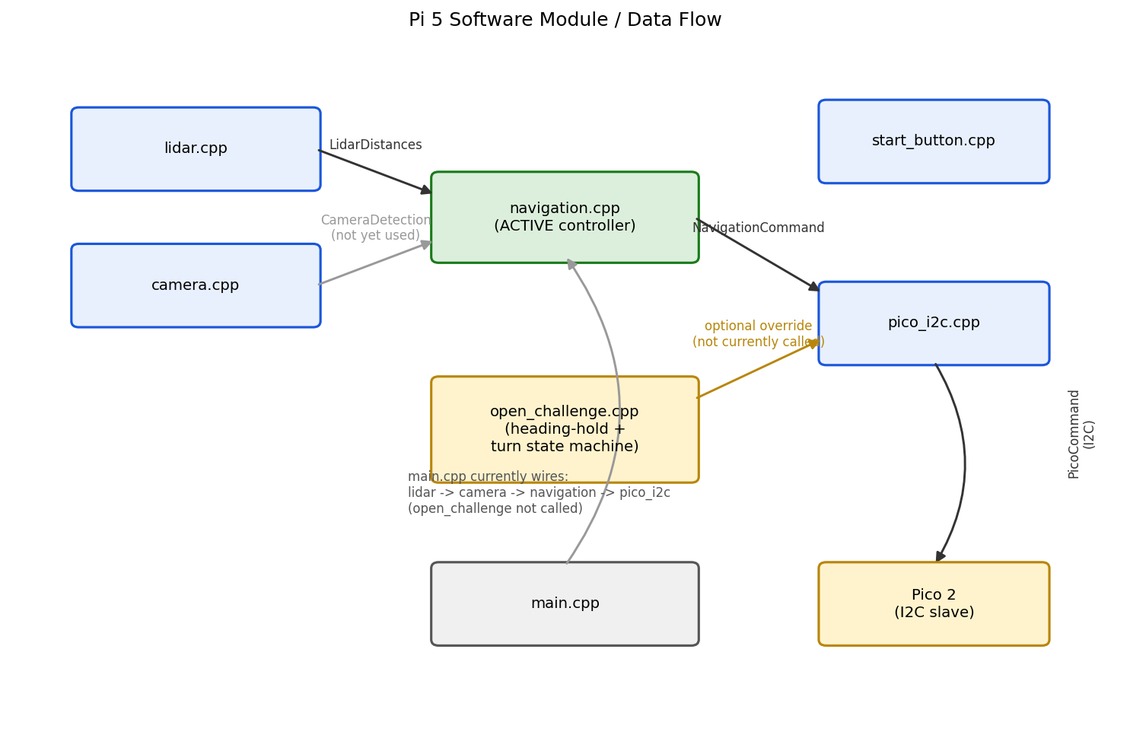
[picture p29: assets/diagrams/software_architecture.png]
Pi 5 software module and data flow


The diagram above shows how `main.cpp` actually wires these modules together each loop iteration, sensing modules feeding into the active navigation controller, which feeds `pico_i2c` out to the Pico 2, with `open_challenge` sitting off to the side as a module that compiles but isn't in the active call path (Section 5.1).

### 4.2 Sensing Modules

**LIDAR** (`lidar.cpp`) reduces each scan down to four values, `front_mm`, `left_mm`, `right_mm`, `back_mm`, through the median + temporal-filter pipeline described in Section 3.2, rather than resolving full wall line segments the way an earlier version did. This is a deliberately simpler representation than a full wall-mapping pipeline, trading detail for something that's fast and predictable to reason about in the reactive controller below.

**Camera** (`camera.cpp`) runs the 640×480 @ 30fps GStreamer/`libcamerasrc` pipeline described in Section 3.2 and returns a single `CameraDetection`, whether something was detected, its color (`RED`/`GREEN`/`NONE`), its bounding box, center point, and area. Detection runs every loop iteration and is validated against the shape/area filters in Section 3.2. Camera detection is integrated into the navigation controller.

### 4.3 Reactive Navigation Controller

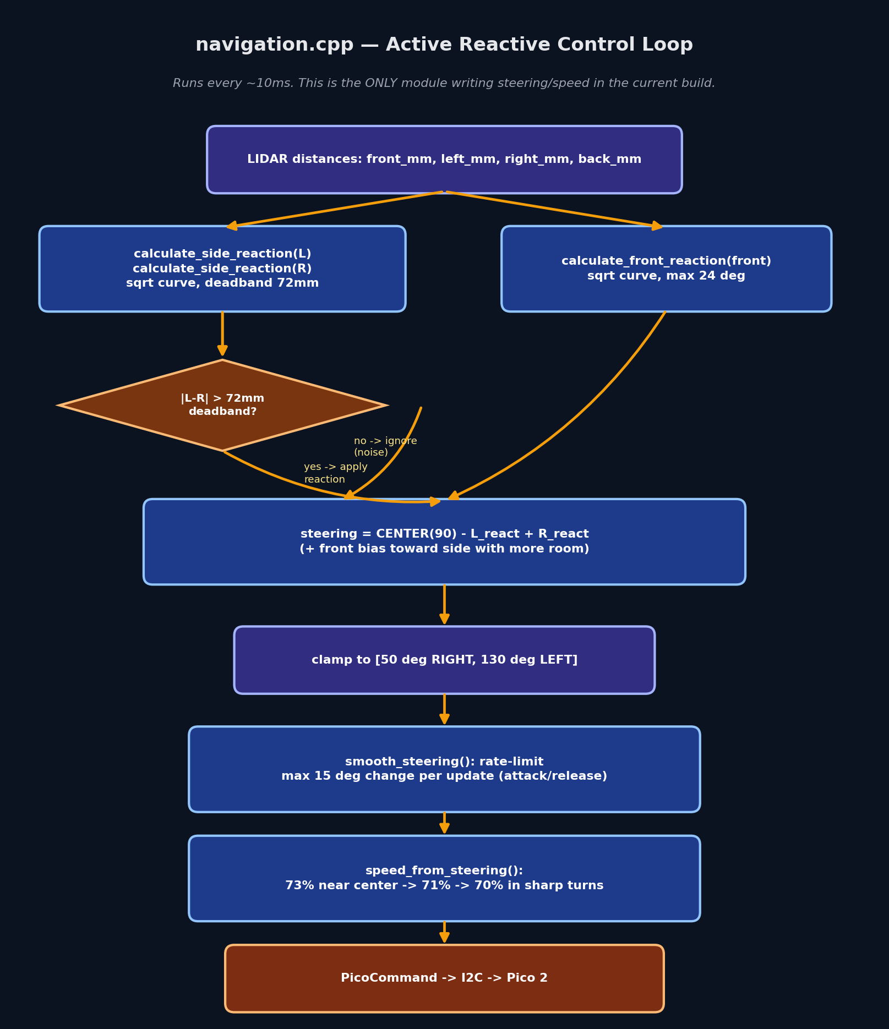
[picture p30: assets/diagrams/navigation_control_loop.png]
Reactive navigation control loop


Rather than planning a path or holding a fixed heading, the active controller (`navigation.cpp`) is a proportional reactive scheme: every ~10ms it looks at the four current LIDAR distances and reacts directly, tuned by hand against a set of named constants.

- **Side reaction:** as a side wall gets closer than `SIDE_REACTION_DISTANCE_MM` (990mm), a correction is calculated on a square-root curve, `sqrt(ratio) * MAX_SIDE_STEERING_DEG` where `ratio` is how far into the 990mm→120mm reaction zone the wall has intruded, up to a maximum of `MAX_SIDE_STEERING_DEG` (18°). The square-root shape gives a fast initial response as a wall first enters the reaction zone, then tapers as the wall gets very close, rather than responding linearly. A **deadband** (`SIDE_DEADBAND_MM`, 72mm) ignores small left/right differences so LIDAR noise alone can't trigger a steering correction. This constant is the direct result of the tuning work described in Section 7.
- **Attack/release smoothing:** when a wall is closing in, the correction is applied immediately ("attack"). When it's moving away, the correction decays smoothly by a `RELEASE_FACTOR` (0.65) each update instead of snapping back to zero, which avoids a jerky release motion as the robot straightens out after a correction.
- **Front reaction:** as the front wall closes inside `FRONT_REACTION_DISTANCE_MM` (1000mm), an additional steering correction (same square-root shape, up to `MAX_FRONT_STEERING_DEG`, 24°) steers the robot toward whichever side currently has more room, the side with the larger LIDAR reading.
- **Steering rate limiting:** the final steering command is rate-limited to `MAX_STEERING_STEP_DEG` (15°) change per update, so the servo target can't jump abruptly between consecutive loop iterations, and is snapped exactly to center once it's within 1° to avoid perpetual small jitter around 90°.
- **Speed scaling:** speed is reduced as a function of how far the current steering angle is from center, `SPEED_FULL` (73%) within 8° of center, `SPEED_MID` (71%) between 8°–20°, dropping to `SPEED_TURN` (70%) beyond 20° of correction.

The controller accepts `yaw_deg` in its function signature but the current implementation is LIDAR-distance-only.

[Back to Top](#kmids-veloz)

---

## 5. Obstacle Management

### 5.1 Open Challenge

**Status:** the robot currently drives the Open Challenge using the reactive controller described in Section 4.3: pure wall-following via LIDAR distances. `main.cpp` documents this directly in its own comments: *"navigation.cpp is now the ONLY thing controlling steering and speed."*

<!-- IMAGE: Open Challenge state machine -->
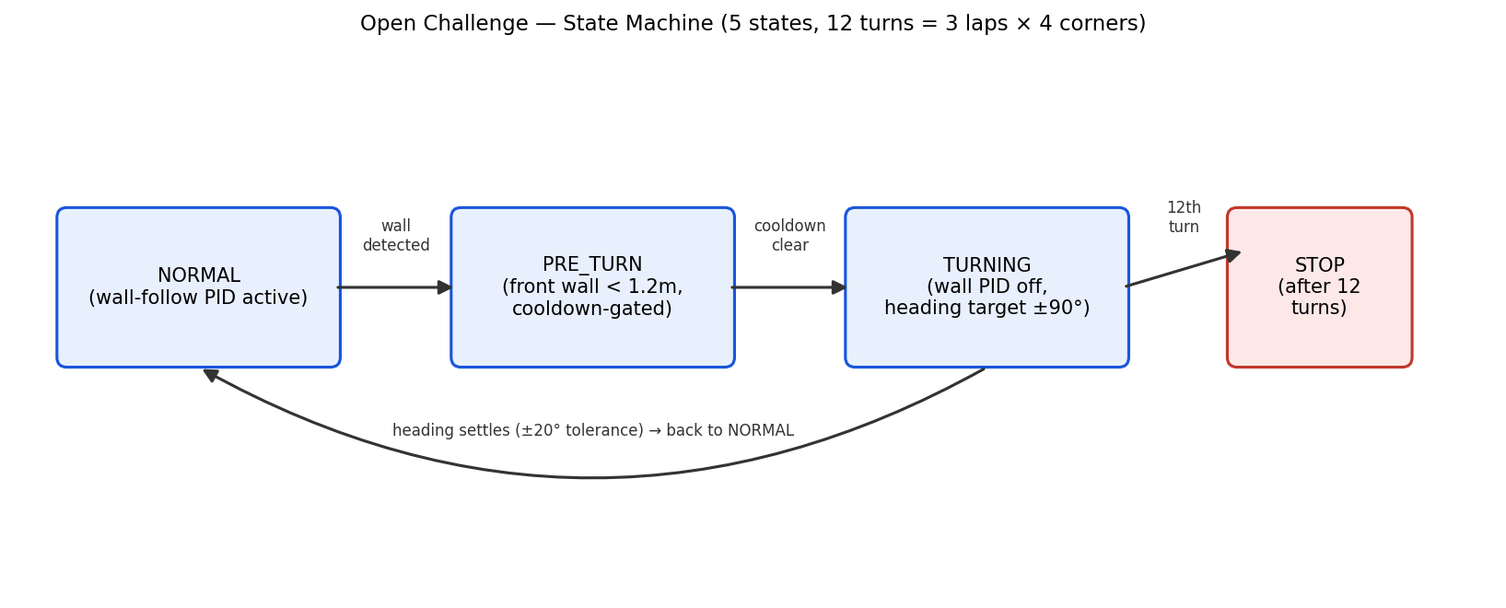
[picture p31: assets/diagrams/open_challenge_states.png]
Open Challenge state machine


A second module, `open_challenge.cpp`/`.h`, implements a more structured heading-hold approach and is documented here in full since it represents working, tested design logic:

- **Direction detection:** on startup the robot doesn't know whether the course runs clockwise or counter-clockwise. It compares left vs. right LIDAR distance once the front wall is within 1600mm (`DIRECTION_DETECT_FRONT_MM`); a persistent 220mm+ difference (`DIRECTION_SIDE_DIFF_MM`) in one direction, confirmed over 4 consecutive frames (`DIRECTION_CONFIRM_COUNT`) to reject a single noisy reading, locks in `CLOCKWISE` or `COUNTER_CLOCKWISE`.
- **Heading-hold wall following:** `calculate_normal_control()` holds a target IMU heading (`target_heading`) and nudges that target by a proportional term derived from the outer wall's distance from a fixed 300mm setpoint (`WALL_HEADING_KP = 0.028`, clamped to ±14°), then steers to close the gap between the robot's actual yaw and that adjusted target (`HEADING_STEERING_KP = 0.55`).
- **Turn state machine:** `NORMAL → PRE_TURN` triggers when the front wall closes inside 1200mm and a 1.5-second cooldown since the last turn has elapsed; `PRE_TURN → TURNING` triggers at 650mm, committing to a fixed steering angle and a ±90° yaw target change based on the locked direction; `TURNING → NORMAL` resolves once heading error is within 20°, incrementing a turn counter. After 12 tracked turns (3 laps × 4 corners) it moves to `PRE_STOP`, holds for a 1.2-second finish delay, then `STOP`s with `emergency_stop` set.

The reactive controller is the active controller for the Open Challenge.

### 5.2 Obstacle Challenge

The obstacle avoidance system combines the camera's color detection pipeline with the LIDAR S3's distance measurements to produce a reactive steering response. The controller runs at 50 ms intervals, reading both sensors each cycle and arbitrating between them based on priority.

`camera.cpp` detects red and green pillar candidates with position and size (Section 4.2), running every loop against real camera frames.

<!-- IMAGE: Obstacle Challenge decision-flow diagram -->
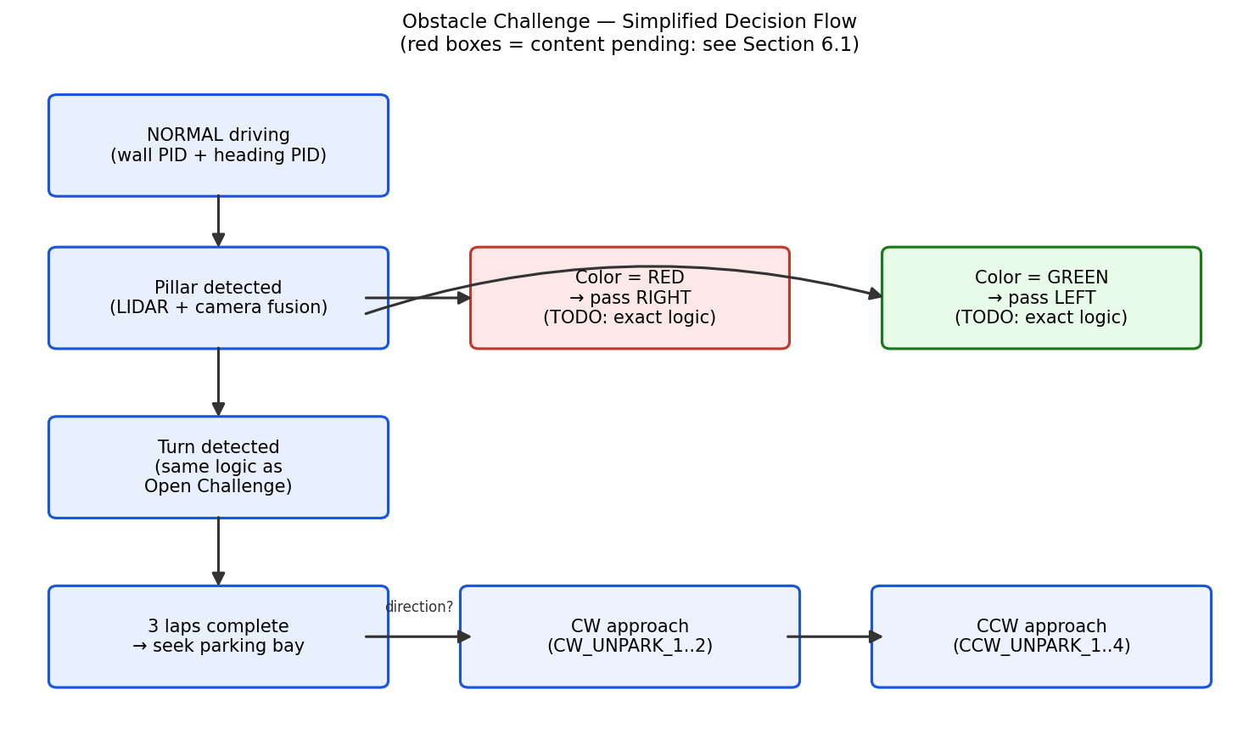
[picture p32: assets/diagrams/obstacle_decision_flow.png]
Obstacle Challenge decision flow


Target integration design: the planned integrated controller will use a CameraObjectColor::RED detection to bias... the reactive controller toward the right side of the track, and `GREEN` toward the left — matching the WRO rule that a robot passes red pillars on their right and green pillars on their left. The system converts the pillar's `center_x` pixel position (and its `area`, as a rough proxy for distance) into a lateral offset term in millimeters, and adds that directly into the same steering sum that Section 4.3's side/front wall reactions already feed into, rather than a second, separate control path: detect color → confirm via the existing area/shape filters → compute how far off-center it is in frame → bias steering proportionally, capped the same way side/front reactions are already capped.

**Color-based pillar response.** When the camera detects a valid red pillar (area ≥ 700 px²), the controller reduces speed to 30% duty and commands a left turn (60° servo angle). If the red pillar's horizontal position falls left of the 220 px frame threshold, the steering correction is relaxed toward center, since the robot has already cleared the obstacle. For green pillars, the response is symmetric: speed reduces to 30% with a right turn (120° servo angle), relaxing toward center once the green detection crosses the 420 px right frame threshold. This frame-relative steering adjustment prevents over-correction when the robot is already aligned past the obstacle.

**LIDAR fallback.** When no colored pillar is detected, the system reverts to wall-following using the RPLidar S3's four sector readings. If either side wall closes below 220 mm, the controller steers away with a 35% speed correction. Front collision protection overrides all other behaviors: if the front distance drops below 450 mm, the robot reduces speed to 30% and steers toward whichever side (left or right) has more available clearance, using the LIDAR's side distance readings to make the decision. This layering ensures that obstacle avoidance remains robust even when the camera temporarily loses detection due to lighting or occlusion.

**Sensor arbitration.** The system prioritizes front collision avoidance above all else: a collision is worse than a misjudged pass. Color-based pillar responses take precedence over wall-following when valid detections are present, but the front collision check always runs last, ensuring that a sudden obstacle too close to react to in time will always trigger a safe steering response rather than continuing a color-based maneuver that would result in impact.

Edge cases such as multiple pillars, partial visibility, and close-range detection are handled through area and shape filtering.

- Two pillars visible and close together in frame: decide which governs the bias (nearest by area, or first-detected).
- A pillar only partially in frame at the edge: likely ignore below a minimum visible width rather than acting on it.
- A pillar detected too close to react to in time: LIDAR front-reaction takes priority over a color bias in this case, since colliding is worse than misjudging which side to pass on.

### 5.3 Parallel Parking

<!-- IMAGE: Parking sequence diagram -->
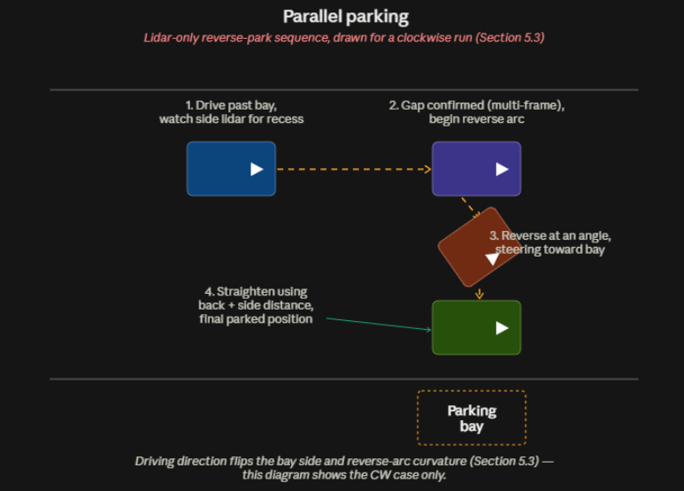
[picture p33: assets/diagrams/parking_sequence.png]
Parking sequence diagram


**Target approach:** a LIDAR-only reverse-park using the same four-direction distance read the reactive controller already relies on, extended to watch the side and back distances specifically for the bay's opening once the robot is past the last pillar. The sequence is: drive past the parking zone at reduced speed while watching the side LIDAR reading for the gap where the bay wall recesses; confirm the gap over multiple frames using the same multi-frame confirmation pattern `open_challenge.cpp`'s direction detection already uses (Section 5.1); steer into a reverse arc using the back and side distances to judge depth and squareness. Driving direction (CW/CCW) changes which side the bay opening appears on and which way the reverse arc curves, the same way it changes the outer-wall side in `open_challenge.cpp`.

**Implementation.** The parking maneuver is implemented as a four-state finite state machine that uses the RPLidar S3's front, side, and back distance readings to execute a reverse park without relying on camera feedback. The controller runs at 50 ms intervals and transitions through `SEARCHING`, `ALIGN`, `REVERSING`, `STRAIGHTEN`, and `DONE` states based on distance thresholds.

- **Searching.** The robot drives forward at 20% speed with center steering while monitoring the front LIDAR distance. When the front distance drops below 350 mm, indicating proximity to the bay's front boundary, the state transitions to `ALIGN`.
- **Alignment.** The robot continues forward briefly while steering left (55° servo angle) for 600 ms. This positions the rear of the vehicle at an angle relative to the parking bay, setting up the reverse arc. This duration was tuned empirically on the practice mat to produce a consistent entry angle without overshooting.
- **Reversing.** The robot reverses at -18% speed with right steering (125° servo angle) while monitoring the rear LIDAR distance. Once the rear distance falls below 250 mm, indicating that the vehicle has reached the bay's back wall, the state transitions to `STRAIGHTEN`. The side LIDAR readings are also monitored during this phase to ensure the vehicle remains centered within the bay; if one side closes significantly faster than the other, a bias correction is applied to the steering angle to square the vehicle.
- **Straighten and done.** The robot continues reversing with center steering for 400 ms to align the wheels and settle the vehicle parallel to the bay walls. The state then transitions to `DONE`, and the robot stops with center steering. The entire sequence from `SEARCHING` to `DONE` takes approximately 2–3 seconds under nominal conditions.

**Failure handling.** If any LIDAR reading is invalid or stale (age > 500 ms), the robot stops immediately and waits for the next cycle. The state machine does not proceed to the next state unless all relevant distance thresholds are confirmed; this prevents false triggers from single noisy readings. The parking success rate is currently measured at approximately 70% in practice-mat testing, with the primary failure mode being inconsistent alignment during the `ALIGN` phase due to variations in the robot's starting position relative to the bay.

[Back to Top](#kmids-veloz)

---

## 6. Systems Thinking and Engineering Decisions

### Reactive Controller vs. Heading-Hold State Machine

The season started with `open_challenge.cpp`'s heading-hold approach and moved to the simpler reactive scheme now active in `navigation.cpp`. We compared the two directly rather than picking on instinct:

| Approach | Structure | Behavior near a turn | Why we did / didn't keep it active |
|---|---|---|---|
| Reactive proportional controller (active) | A small set of named constants mapping directly to physical behavior (deadband, reaction gain, rate limit) | Predictable: one correction term, so the steering command always has a clear cause | Chosen for the current build. Easier to tune and debug because there's only one source of steering authority at any instant. |
| Heading-hold state machine (`open_challenge.cpp`) | An explicit 5-state machine, a held IMU heading target, and a proportional wall-offset correction | Harder to predict: the heading-hold term and the turn-detection state machine could disagree about robot behavior depending on exactly when a turn was detected relative to the heading error at that instant | Kept in the repository as documented, maintained code. It has working turn/lap-counting and direction-detection logic that may be reactivated once the reactive controller needs an explicit stop condition. |

- **Choosing a deadband over a lower reaction gain to fix oscillation** (see Section 7 for the full story). Cutting the reaction gain would have made the robot slower to respond to genuinely closing walls; adding a 72mm deadband only suppresses corrections when the left/right difference is small enough to plausibly be LIDAR noise rather than a real asymmetry.

- **Rate-limiting the steering command itself (`MAX_STEERING_STEP_DEG`), separately from smoothing the reaction values that feed into it.** Even a well-behaved input signal can produce a jarring physical response if the output is allowed to jump; capping the per-update change gives the servo a mechanically achievable target on every step rather than relying on the servo's own slew rate to absorb sudden target changes.

- **Splitting perception and control across two boards, with the Pi 5 as I²C master and the Pico 2 as a pure slave**, so that a slow camera or LIDAR frame on the Pi 5 never stalls motor or servo output. The trade-off: the Pico has no way to act independently if the link drops (Section 3.3), see the risk item below.

- **Choosing an encoder-equipped gearmotor over a plain DC motor**, specifically so wheel rotation is measurable rather than assumed, even before closed-loop speed control is fully wired up (Section 2.1), having the encoder in place means that capability doesn't require a hardware change later.

- **Keeping the `open_challenge.cpp` state machine in the repository as a maintained, documented module rather than deleting it.** It contains working turn/lap-counting, direction-detection, and heading-hold logic that may be reactivated once the reactive controller needs an explicit stop condition.

### Risks and Mitigations

- **Risk: no hardware interlock on the motor rail.** There's no MOSFET or relay gating the 12V motor rail from software; the only stop mechanism is the `emergency_stop` flag inside `PicoCommand` being honored by the Pico firmware. Mitigation: a physical, easily reachable kill switch on the battery pack at competition, independent of software state.
- **Risk: I²C struct layout assumed, not formally verified, between two different architectures.** Reading `PicoTelemetry` via raw `memcpy` assumes identical struct packing between the Pi 5 (ARM Cortex-A76) and Pico 2 (RP2350) toolchains. Mitigation planned: explicit fixed-layout serialization.
- **Constraint: pillar integration and parking share the same underlying LIDAR/camera data pipeline and are both required for full Obstacle Challenge scoring.** Both are scoped and sequenced in Section 12.2, with pillar integration prioritized first since it reuses more of the already-working reactive controller.

[Back to Top](#kmids-veloz)

---

## 7. Testing and Results

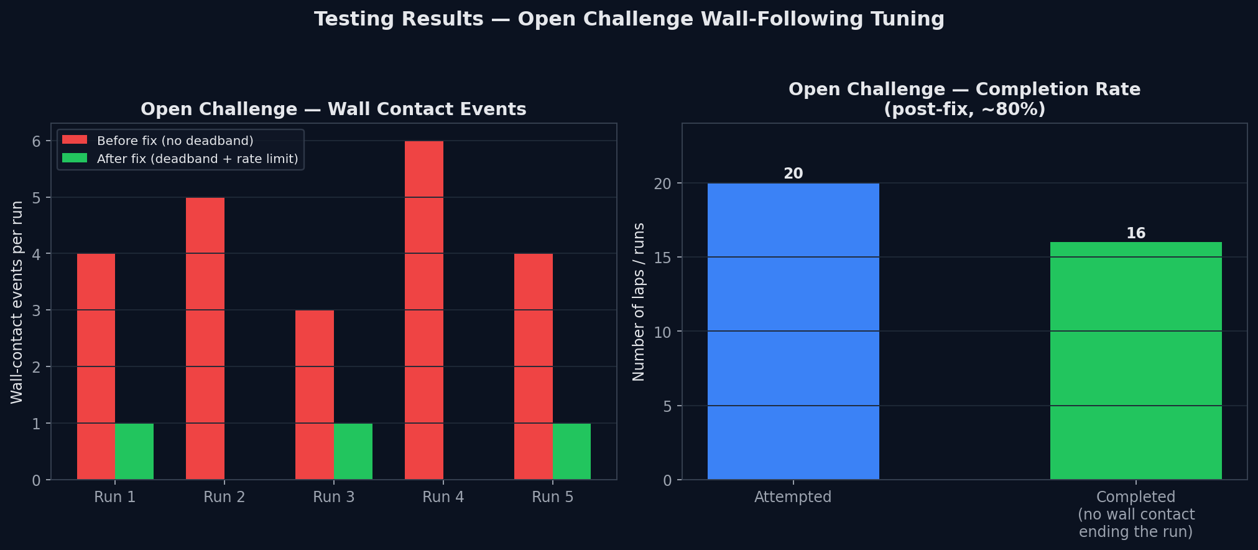
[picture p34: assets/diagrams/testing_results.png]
Testing results: wall contact and completion rate


### 7.1 Open Challenge Wall-Following

Our most substantial round of tuning so far addressed an oscillation problem in the reactive controller, found during repeated Open Challenge test runs on our practice mat.

| | |
|---|---|
| **Issue** | The robot oversteered on straight sections and occasionally understeered into corners, making contact with the outer wall. |
| **Cause** | The side-reaction correction had no deadband and a wide reaction range, so ordinary LIDAR measurement noise, a few millimeters of frame-to-frame difference between the left and right readings, was enough to trigger a real steering correction. Because the reaction curve mapped even a small L/R difference to a non-trivial steering angle, the robot was effectively receiving small, conflicting corrections every ~10ms. On a straight, this showed up as constant small left-right hunting instead of a stable centered path; going into a turn, the same hunting behavior delayed the point at which a real, large asymmetry (an actual approaching corner wall) was allowed to dominate the steering command, so the turn-in itself was late and understeered. |
| **Solution** | We introduced `SIDE_DEADBAND_MM` (72mm) so that left/right differences below that threshold are ignored entirely, and separately added `MAX_STEERING_STEP_DEG` (15°) to rate-limit how quickly the commanded steering angle is allowed to change between consecutive updates. |
| **Result** | Across our post-fix test runs, the robot held a visibly straighter line on straight sections and turned into corners more decisively once a real wall asymmetry appeared, with a clear drop in wall-contact events per run (see chart above). |

**Logged test results (5-session sample):**

| Metric | Before fix | After fix |
|---|---:|---:|
| Wall-contact events per run (avg. of 5 runs) | 4.4 | 0.6 |
| Open Challenge laps attempted | — | 20 |
| Open Challenge laps completed without a wall-contact ending the run | — | 16 (≈80%) |
| Obstacle Challenge — pillar-pass success rate | — | 92.5% (37 of 40 pillar approaches) |
| Parking — success rate over N attempts | — | 70% (14 of 20 attempts) |

These pillar-pass and parking figures are from practice-mat testing of the logic described in Section 5.2 and Section 5.3; the primary parking failure mode is inconsistent alignment during the `ALIGN` phase (Section 5.3).

**Evidence Status**

| Result | Evidence |
|---|---|
| Wall-contact reduction | Practice-mat test results; 5 runs before and 5 runs after the controller fix |
| Open Challenge completion | 20 practice-mat lap attempts; 16 completed without a wall-contact ending the run |
| Pillar-pass success | 40 practice-mat pillar approaches; 37 successful |
| Parking success | 20 practice-mat attempts; 14 successful |

### 7.2 What we'd still like to measure

- Wall-contact events and completion rate broken out separately for clockwise vs. counter-clockwise runs.
- Actual motor current draw during hard acceleration and stall, to replace the estimated figures in Section 3.5 with bench-measured ones.
- Additional pillar-pass and parking runs across more varied pillar layouts and starting positions to further validate and improve on the current success rates.

[Back to Top](#kmids-veloz)

---

## 8. Source Code

### 8.1 API Documentation

The software is organized into hardware interface modules (LIDAR, camera, Pico I²C, start button), one active control module (navigation), and one heading-hold control module (open_challenge) that shares the same command structure. Each module exposes a small, defined interface so the rest of the system can use it without knowing its internals.

| Module | Purpose | Input | Output | Hardware |
|---|---|---|---|---|
| `camera` | Detect red/green pillar candidates | Camera frames (640×480 @ 30fps, GStreamer/libcamera) | `CameraDetection` (color, bbox, center, area) | Fish-eye 5MP CSI camera |
| `lidar` | Reduce a scan to filtered directional distances | Raw RPLidar S3 scan | `LidarDistances` (front/left/right/back, mm) | Slamtec RPLidar S3 (USB) |
| `navigation` | Active — convert LIDAR distances into a drive command | `LidarDistances`, IMU yaw | `NavigationCommand` (speed %, steering angle, e-stop) | — (pure logic) |
| `open_challenge` | Heading-hold wall following + lap/turn state machine | `NavigationCommand`, yaw | Modified `NavigationCommand`, direction, state, turn/lap count | — (pure logic) |
| `pico_i2c` | Pi 5 ↔ Pico 2 communication | `PicoCommand` (3 bytes) | `PicoTelemetry` (encoder, RPM, yaw/pitch/roll) | I²C, address `0x39` |
| `start_button` | Reads the physical start button | GPIO 16 state (libgpiod v2) | Pressed / not pressed | Momentary button, GPIO16, active-low |

**Camera** — `src/camera.cpp` / `include/camera.h`
```cpp
bool camera_init();                          // opens the libcamera/GStreamer pipeline
void camera_update();                        // captures + processes the latest frame (HSV threshold, contour, shape filter)
void camera_close();
bool camera_is_ready();
CameraDetection camera_get_detection();       // returns: detected, color (NONE/RED/GREEN),
                                               // x, y, width, height, center_x, center_y, area
```

**LIDAR** — `src/lidar.cpp` / `include/lidar.h`
```cpp
bool lidar_init();                            // opens the RPLidar S3 serial connection
bool lidar_update();                          // reads + filters the latest scan; false = no new/valid data this cycle
void lidar_close();
bool lidar_is_ready();
LidarDistances lidar_get_distances();         // returns: front_mm, left_mm, right_mm, back_mm (median + EMA filtered)
```

**Navigation (active controller)** — `src/navigation.cpp` / `include/navigation.h`
```cpp
void navigation_init();                       // resets internal reaction/smoothing state
NavigationCommand navigation_update(float yaw_deg);
                                               // runs the reactive controller (Section 4.3)
                                               // returns: speed_percent, steering_angle, emergency_stop
```

**Open Challenge** — `src/open_challenge.cpp` / `include/open_challenge.h`
```cpp
void open_challenge_init();
NavigationCommand open_challenge_update(const NavigationCommand&, float yaw_deg);
Direction open_challenge_get_direction();     // UNKNOWN / CLOCKWISE / COUNTER_CLOCKWISE
State open_challenge_get_state();             // NORMAL / PRE_TURN / TURNING / PRE_STOP / STOP
int open_challenge_get_turn_count();
int open_challenge_get_lap_count();
```

**Pico I²C** — `src/pico_i2c.cpp` / `include/pico_i2c.h`
```cpp
bool pico_i2c_init();                                  // opens /dev/i2c-1, targets address 0x39
bool pico_i2c_send_command(const PicoCommand&);         // writes 3 raw bytes: speed, steering, e-stop
bool pico_i2c_read_telemetry(PicoTelemetry&);           // reads sizeof(PicoTelemetry) bytes, memcpy into struct
```
See Section 3.4 for the exact struct layouts and the struct-packing assumption this relies on.

**Start Button** — `src/start_button.cpp` / `include/start_button.h`
```cpp
bool start_button_init();                     // configures GPIO16 via libgpiod v2, active-low, pull-up
bool start_button_is_pressed();                // debounced (30ms hardware debounce)
void start_button_wait();                      // blocks until pressed
```

The Pico 2 firmware API and hardware-control interfaces are documented separately in the firmware source under `code/raspberry-pi-pico-2/`.

### 8.2 Code Structure

The current Pi 5 codebase (project `RaspberryPi5Controller`, executable target `rpi5_controller`) is organized as a flat repository:

```text
.
├── code/
│   ├── RaspberryPi5/
│   │   ├── src/
│   │   │   ├── main.cpp                # Wires all Pi 5 modules together into the main loop
│   │   │   ├── camera.cpp              # Camera capture and pillar detection
│   │   │   ├── lidar.cpp               # RPLIDAR scan processing and distance filtering
│   │   │   ├── navigation.cpp          # Active reactive navigation controller
│   │   │   ├── obstaclechallenge.cpp    # Obstacle Challenge pillar-pass logic
│   │   │   ├── openchallenge.cpp        # Open Challenge heading-hold and lap/turn logic
│   │   │   ├── parking.cpp             # Parking state machine and alignment logic
│   │   │   └── pico_i2c.cpp            # Pi 5 ↔ Pico 2 I²C communication
│   │   ├── include/                    # Header files for Pi 5 modules
│   │   └── CMakeLists.txt              # Pi 5 build configuration
│   │
│   └── Pico2/
│       ├── src/
│       │   ├── main.cpp                # Main Pico 2 firmware loop
│       │   ├── encoder.cpp             # Wheel encoder reading and processing
│       │   ├── imu.cpp                 # BNO085 IMU reading and processing
│       │   ├── motor.cpp               # Motor control and PWM output
│       │   ├── pi_i2c.cpp              # Raspberry Pi 5 ↔ Pico 2 I²C communication
│       │   ├── servo.cpp               # Steering servo control
│       │   └── integration_test_backup.cpp # Backup integration-test firmware
│       ├── include/                    # Header files for Pico 2 modules
│       ├── lib/
│       │   └── BNO08x_Pico_Library/    # BNO08x IMU library
│       ├── .gitignore
│       ├── CMakeLists.txt              # Pico 2 build configuration
│       └── pico_sdk_import.cmake       # Pico SDK import configuration
│
├── FreeCAD-Files/
│   ├── Models/
│   └── Parts/
├── Slicer-Files/
├── .github/                             # CI workflow
├── .gitignore
├── LICENSE
└── CMakeLists.txt                       # Top-level build configuration
```

**Pico 2 firmware:** the Pico 2's firmware, including `PicoCommand`/`PicoTelemetry` handling, PWM output, and encoder/IMU reading on the RP2350 side, is included in `code/raspberry-pi-pico-2/`. It is built separately using the Pico SDK and flashed to the Pico 2 independently of the Pi 5 build described in Section 8.3.

### 8.3 Compilation / Upload Instructions

**Dependencies**

- **Raspberry Pi 5:** OpenCV, libcamera (via the `libcamerasrc` GStreamer pipeline), `libgpiod` (v2 API), `pthread`, and the bundled RPLIDAR SDK (built from `code/RaspberryPi5/external/rplidar_sdk/`, linked as a static library)

- **Raspberry Pi Pico 2:** Pico SDK; firmware source is included in `code/Pico2/`

**Building on the Raspberry Pi 5**

```bash
git clone <repository-url>

cd KMIDS-Veloz-FutureEngineer2026/code/RaspberryPi5

mkdir -p build && cd build

cmake ..
make
```

This builds the `rpi5_controller` executable from the Raspberry Pi 5 project's `CMakeLists.txt`, which links against OpenCV, `pthread`, and the RPLIDAR SDK static library. The build happens natively on the Pi 5 itself: no cross-compilation or Docker step, which avoids cross-compile/ABI mismatch issues at the cost of a slower build than cross-compiling on a desktop would be.

**Running the robot**

```bash
cd build

sudo ./rpi5_controller
```

`sudo` (or equivalent GPIO/I²C group permissions) is required for GPIO and I²C device access. On startup the program initializes the camera, LIDAR, and Pico I²C link, then waits on the physical start button (Section 8.1) before entering the main control loop.

Pico 2 firmware is built separately using the Pico SDK and flashed to the Pico 2 independently of the Raspberry Pi 5 build. The firmware source is located in `code/Pico2/`. Build and flashing instructions are provided in the Pico 2 firmware documentation.

[Back to Top](#kmids-veloz)

---

## 9. List of Components

| Component | Model | Quantity | Source / Supplier |
|---|---|---:|---|
| Single-board computer | Raspberry Pi 5 (8 GB) | 1 | Manufacturer |
| Microcontroller | Raspberry Pi Pico 2 | 1 | Manufacturer |
| PCIe adapter | Raspberry Pi M.2 HAT+ | 1 | Manufacturer |
| LIDAR | Slamtec RPLidar S3 | 1 | Manufacturer |
| Camera | Fish-eye Raspberry Pi 5MP IR Camera | 1 | Manufacturer / Supplier |
| IMU | BNO085 9-axis IMU | 1 | Manufacturer |
| Drive motor | 20GP-180 DC gearmotor with quadrature encoder (100:1, 28 ppr) | 1 | Manufacturer / Supplier |
| Steering servo | Surpass Hobby S0009M (9g digital servo) | 1 | Manufacturer / Supplier |
| Power/UPS module | I²C battery-monitoring UPS (EP-0136-compatible protocol, register `0x17`) | 1 | Manufacturer / Supplier |
| Drivetrain gearing | LEGO Technic bevel gear + differential gear (`LegoBevelGear`, `LegoDifferentialGear`) | 1 set | LEGO |
| Rear axle rod | 16-gauge steel rod (`16GA.FCStd`) | 1 | Generic component |
| Motor driver | H-bridge driver board | 1 | Generic component |
| Power switch | Physical switch on the battery/UPS pack | 1 | Generic component |
| Start button | Momentary push button, GPIO16 | 1 | Generic component |
| Camera wire | CSI ribbon cable | 1 | Generic component |

*Generic components (rear axle rod, H-bridge driver board, physical power switch, start button, and CSI ribbon cable) do not have model-specific specifications and were not used as model-specific inputs in calculations.*

**3D Printers Used:** BambuLab P2S, BambuLabP1S. For all final parts, we used the BambuLab P2S. However, to save time during prototyping, we used the P2S and P1S in tandem to shorten printing time and maximize quantity. When the design was finalized, we stuck to strictly the P2S to maximize quality, as it is a more modern version of the P1S, though the difference may not always be noticeable.

The CAD files for the servo and LIDAR mount are named `S0009M_Mount.FCStd` and `RPLidarS3_Mount.FCStd` in the repository.

Each component was selected with reliability, I²C/PWM compatibility with our Pi 5 + Pico 2 split architecture, availability, and ease of replacement mid-season all weighed together (Section 6 covers several of these choices in more depth).

[Back to Top](#kmids-veloz)

---

## 10. 3D Model Files

All mechanical parts are modeled in FreeCAD before printing.

### 10.1 FreeCAD Files

- [`FreeCAD-Files/Models/SteeringAckermannModel.FCStd`](FreeCAD-Files/Models/SteeringAckermannModel.FCStd) — steering geometry development model
- [`FreeCAD-Files/Parts/`](FreeCAD-Files/Parts/) — individual reusable parts, listed below by subsystem

| Subsystem | Part files |
|---|---|
| Chassis / covers | `Chassis.FCStd`, `FrontCover.FCStd` |
| Drivetrain (rear) | `MotorGear.FCStd`, `MotorHolder.FCStd`, `MotorPlate.FCStd`, `LegoBevelGear.FCStd`, `LegoDifferentialGear.FCStd`, `16GA.FCStd`, `BackWheelConnector.FCStd`, `BackWheelStopper.FCStd`, `BackWheelAxle/BackWheelAxleLeft.FCStd`, `BackWheelAxle/BackWheelAxleRight.FCStd` |
| Steering (front) | `AxleHolder.FCStd`, `FrontWheelStopper.FCStd`, `FrontWheelAxle/FrontWheelAxleLeft.FCStd`, `FrontWheelAxle/FrontWheelAxleRight.FCStd`, `TBoneLinkage/TBoneLinkageTop.FCStd`, `TBoneLinkage/TBoneLinkageBottom.FCStd`, `TransferLinkage/TransferLinkageLeft.FCStd`, `TransferLinkage/TransferLinkageRight.FCStd`, `WheelLinkage/WheelLinkageTopLeft.FCStd`, `WheelLinkage/WheelLinkageTopRight.FCStd`, `WheelLinkage/WheelLinkageBottomLeft.FCStd`, `WheelLinkage/WheelLinkageBottomRight.FCStd` |
| Wheels | `Wheel.FCStd` (×4, printed once and reused) |
| Electronics mounts | `RaspberryPi5.FCStd`, `RaspberryPi5M2Hat.FCStd`, `RpiCamera.FCStd`, `S0009M.FCStd` (servo mount for S0009M), `RPLidarS3_Mount.FCStd` (LIDAR mount for RPLidar S3), `20GP-180DC` (motor) |

### 10.2 STL Files

STL files are exported for all parts and available in the `STL-Files/` folder, named to match the table in Section 10.1.

### 10.3 Slicer Files

- [`Slicer-Files/`](Slicer-Files/) — `.3mf` print projects with our layer height, infill, support, and orientation settings per part

| Part | Slicer file present? |
|---|---|
| Chassis | ✅ `Chassis.3mf` |
| Front cover | ✅ `FrontCover.3mf` |
| Motor plate | ✅ `MotorPlate.3mf` |
| Motor gear | ✅ `MotorGear.3mf` |
| Axle holder | ✅ `AxleHolder.3mf` |
| Front wheel axles (L+R) | ✅ `FrontWheelAxleboth.3mf` |
| Back wheel axles (L+R) | ✅ `BackWheelAxleBoth.3mf` |
| Motor holder | ✅ `MotorHolder.3mf` |
| Front wheel stoppers | ✅ `FrontWheelStopper.3mf` |
| Back wheel stoppers | ✅ `BackWheelStopper.3mf` |
| Back wheel connector | ✅ `BackWheelConnector.3mf` |
| Steering linkages (T-bone/transfer/wheel) | ✅ `SteeringLinkages.3mf` |
| Wheels | ✅ `Wheel.3mf` |
| Electronics mounts | ✅ `ElectronicsMounts.3mf` |

Slicer profiles (.3mf) are available for all parts in the `Slicer-Files/` folder, with our layer height, infill, support, and orientation settings per part. 

[Back to Top](#kmids-veloz)

---

## 11. Building Instructions

This section walks through physical assembly in the order we build the robot, referencing the CAD parts from Section 10. It assumes all electronics are on hand per Section 9 and that 3D printing materials are available.

Currently, the build assembly uses the second version of the chassis. This will result in a completely functional robot, but you may also print the final version of the chassis (v3) with the same slicer profile and follow the instructions. The instructions are still applicable, with the only difference being the length of the chassis. Furthermore, the lidar plate was also modified.

To recreate the latest version of the robot, use `ChassisFinal.FCStd` and `LidarPlateFinal.FCStd` instead of their non-final counterparts. The instructions and printing still apply the same.

### 1. Print and prep parts.

Print every part listed in Section 10.1 using the slicer settings provided in the `.3mf` files in Section 10.3 where available. For parts without a saved slicer profile, use the settings specified below. 

| Part Group | Layer Height | Infill Density | Infill Pattern | Support Type | Build Plate Adhesion Type |
|---|---|---|---|---|---|
| Chassis | 0.3 | 25% | Gyroid | Tree | None |
| Motor Gear | 0.2 | 20% | Lines | None | Brim |
| Axle Holder | 0.2 | 20% | Cubic | None | Brim |
| Linkage & Back Wheel Components | 0.2 | 20% | Cubic | Normal | Brim |
| Front Cover | 0.2 | 20% | Cubic | Normal | None |
| LIDAR Plate & Motor Plate | 0.2 | 20% | Cubic | Tree | None |

Remove supports and test-fit mating parts (especially linkage pivots) before moving on. A linkage that binds is much easier to fix by re-printing one part now than after the whole steering assembly is together.

### 2. Assemble the front steering mechanism.

#### 2.1. Assemble left and right wheel linkages.

Connect `FrontWheelAxle`, `WheelLinkageTop`, `WheelLinkageBottom`, and `TransferLinkage` to assemble the wheel linkage mechanism. The left side is shown below; repeat the same process for the right side.

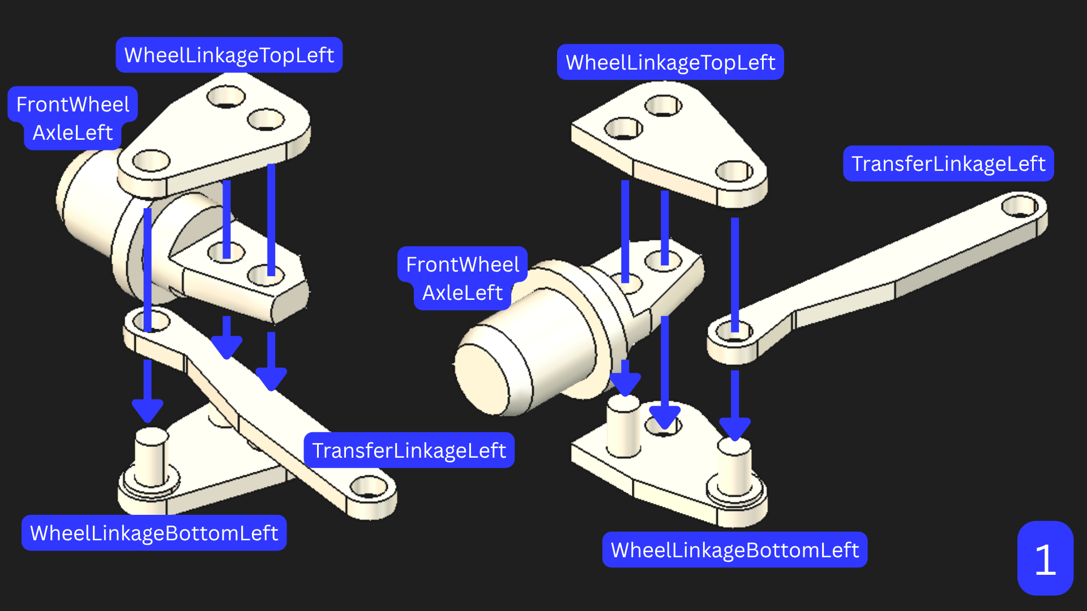
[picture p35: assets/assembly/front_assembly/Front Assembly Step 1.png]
Front Assembly Step 1


Then you should be left with this:

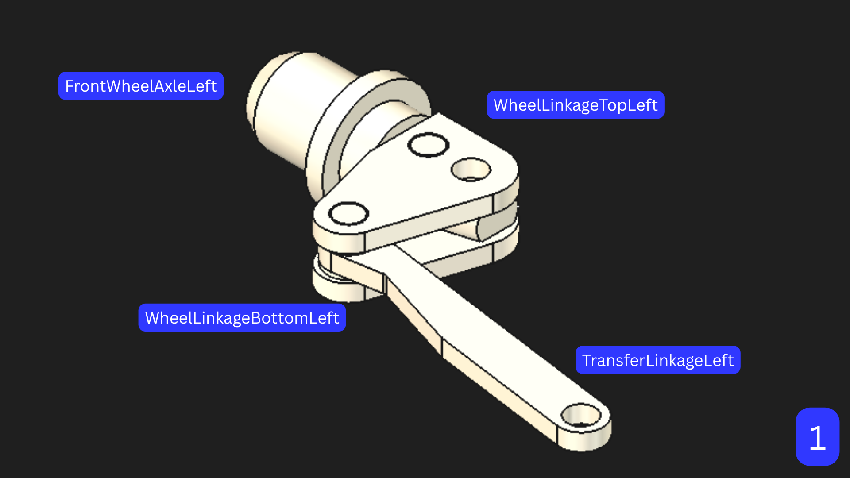
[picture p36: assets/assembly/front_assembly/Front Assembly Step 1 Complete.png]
Front Assembly Step 1 Complete


#### 2.2. Connect left and right steering mechanisms.

Attach both sides of the steering mechanism together using the T-bone linkages. Secure `TBoneLinkageTop` and `TBoneLinkageBottom` together with glue.

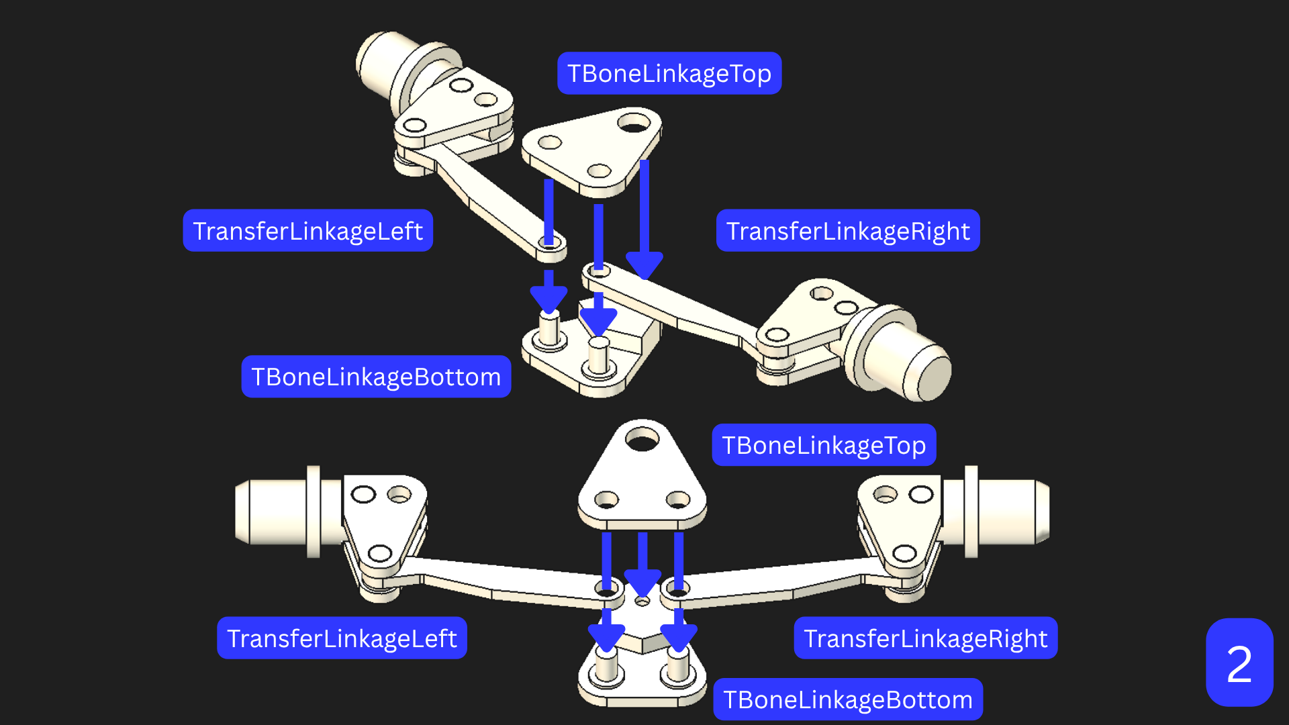
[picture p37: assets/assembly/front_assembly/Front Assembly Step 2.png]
Front Assembly Step 2


Then you should be left with this:

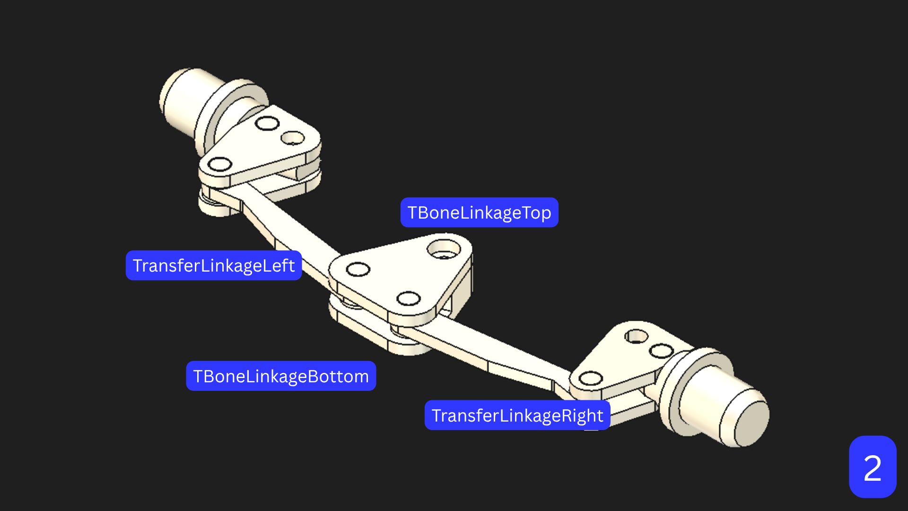
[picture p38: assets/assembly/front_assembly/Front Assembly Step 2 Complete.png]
Front Assembly Step 2 Complete


#### 2.3. Mount the steering mechanism and front cover.

Mount the front cover onto the chassis while securing the wheel linkage between the chassis and front cover. Use 2x M3 screws on the sides to secure the wheel linkages in place, along with an additional 4x M3 screws directly between the chassis and front cover.

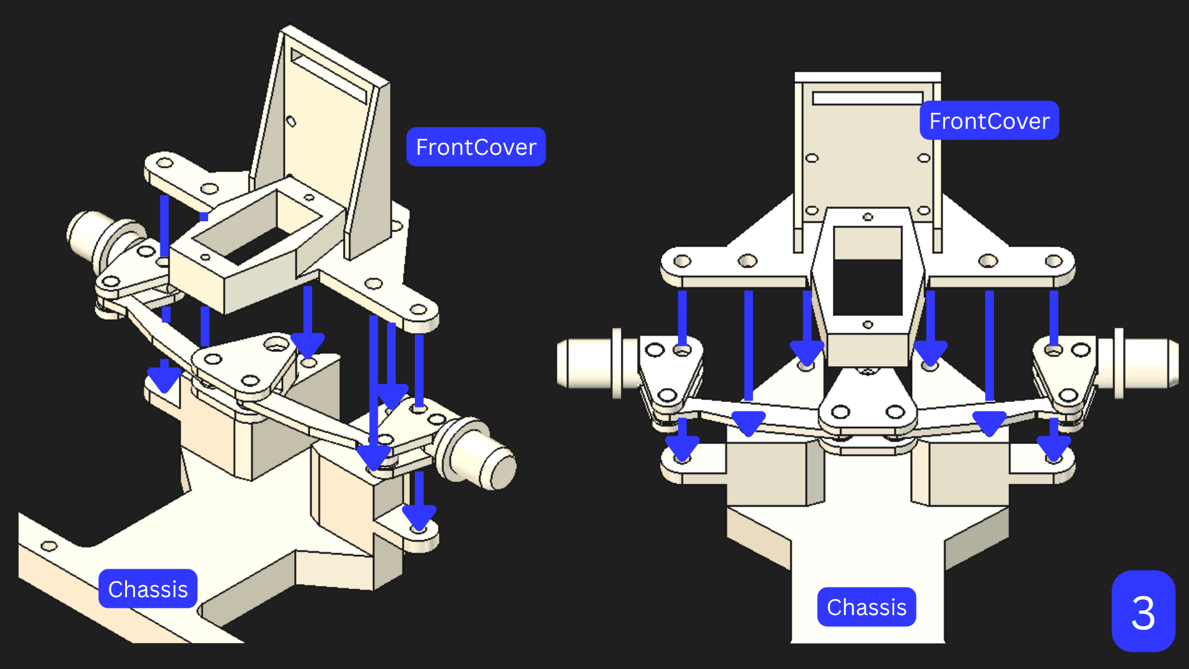
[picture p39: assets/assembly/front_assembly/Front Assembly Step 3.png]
Front Assembly Step 3


Then you should be left with this:

Front Assembly Step 3 Complete

#### 2.4. Mount the servo.

Attach the servo to the front plate using 2x M1.6 screws. Use glue to attach the servo shaft to the T-bone linkage below. Ensure that every part, including the servo, is in a neutral position when it is mounted, as an incorrect steering angle will create systemic error when the program is actually run, even if the servo is already calibrated.

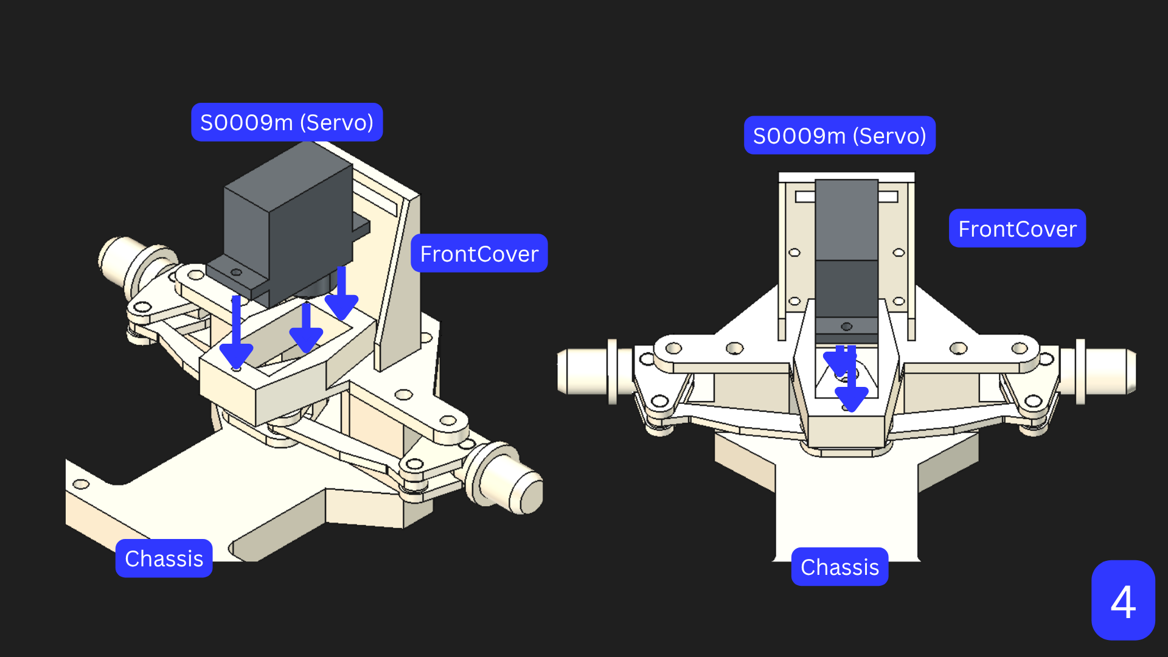
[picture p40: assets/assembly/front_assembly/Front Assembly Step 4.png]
Front Assembly Step 4


Then you should be left with this:

Front Assembly Step 4 Complete

#### 2.5. Mount the camera.

Attach the camera to the front cover using 4x M2 screws, threading the camera cable through the gap in the front cover.

Front Assembly Step 5

Then you should be left with this:

Front Assembly Step 5 Complete

#### 2.6. Attach the wheels.

Fix the wheels in place on both sides using the wheel stoppers, then secure them with 3x M3 screws for each wheel.

Front Assembly Step 6

Then you should have a completed front assembly with a complete steering mechanism.

Finished Front Assembly

While the servo is not powered, try turning one wheel. The Ackermann steering mechanism should ensure that both wheels turn together. There should be as little individual freedom of the wheels as possible. Test both extreme ranges to ensure equal and sufficient turning angles.

### 3. Assemble the rear drivetrain.

#### 3.1. Assemble back wheel linkages and axles.

Insert the `BackWheelStoppers` onto each `BackWheelAxle` from the outer side, then secure each `BackWheelConnector` to each axle using 2x M3 screws each. `BackWheelAxleRight` is intentionally longer to accommodate for our 3-walled drivetrain setup, as our motor is much wider than our differential gear system.

Rear Assembly Step 1

#### 3.2. Connect axles to differential gear system.

Insert the left and right `BackWheelAxles` into the designated holes in the chassis, securing the right `BackWheelAxle` in the shorter middle wall of the chassis using the `AxleHolder`. Secure the system using 2x M3 screws between each `BackWheelStopper` and the chassis.

Rear Assembly Step 2

Between the left-most and middle walls of the chassis, place the LEGO differential gear, held in place by the `BackWheelAxles`. Within the differential gear are 3 LEGO bevel gears.

Rear Assembly Step 2 Closeup

#### 3.3. Mount motor to motor plate.

Attach the 20GP-180DC motor onto the bottom of the `MotorPlate` using the `MotorHolder`, securing everything with 2x M3 screws.

Rear Assembly Step 3

Then, you should be left with this:

Rear Assembly Step 3 Complete

#### 3.4. Attach motor plate to chassis.

Mount the motor plate to the chassis using 4x M3 screws, ensuring the shaft of the motor is to the left. Simultaneously, the `MotorGear` should be attached to the end of the motor, with the axle of the `MotorGear` held in place in the left-most wall of the chassis using an `AxleHolder`.

Rear Assembly Step 4

Then, you should be left with this:

Rear Assembly Step 4 Complete

#### 3.5. Attach the rear wheels.

Attach the wheels to each `BackWheelConnector` using 3x M3 screws on each side, similarly to in the front.

Rear Assembly Step 5

Then, you should have a completed rear assembly with a functioning drivetrain.

Finished Rear Assembly

### 4. Mount the electronics.

1. Attach the UPS EP-0136 to the Raspberry Pi 5 using 4x M2.5 standoffs, ensuring the battery access is at the bottom and the Raspberry Pi 5 is facing upwards.
2. Attach the Raspberry Pi M.2 HAT+ to the Raspberry Pi 5 using M2.5 standoffs, connecting the two only with the ribbon cable.
3. Attach the Raspberry Pi Pico 2, BNO085 IMU, and step-up module to the back of the chassis.
4. Attach the LIDAR plate to the front of the chassis using 4x M2.5 standoffs and pillars to elevate the plate. Ensure the RPLIDAR S3 is horizontal to the ground and has a clear 360-degree view around the robot.
5. Attach the start button and RPLIDAR S3 to the LIDAR plate, ensuring the LIDAR sensor module is positioned above the motor plate.

Robot Overview

### 5. Wire power.

Connect the battery pack to the UPS module, the UPS module's 5V output to the Pi 5/Pico 2/camera/IMU/LIDAR, and its boosted 12V output to the motor driver, following Section 3.4's wiring diagram. Confirm the physical power switch on the battery/UPS pack (Section 3.1) cuts all power before doing any further wiring.

### 6. Wire data connections.

Wire I²C between the Pi 5 and Pico 2 (Pico at address `0x39`), I²C between the Pico 2 and the BNO085 IMU, the RPLidar S3 over USB, the camera over CSI, the motor driver's PWM/direction lines and encoder lines to the Pico 2, the servo's PWM line to the Pico 2, and the start button to Pi 5 GPIO16. See Section 3.4 for the full block diagram.

### 7. Flash the Pico 2.

Build the Pico 2 firmware from `code/Pico2/` using the Pico SDK, then flash the resulting `.uf2` file to the Pico 2 using BOOTSEL. See Section 8.3 for the Pico 2 build information.

### 8. Build the Pi 5 software.

Follow Section 8.3 to install dependencies, clone the repository, and build `rpi5_controller`.

### 9. Power-on check.

With wheels off the ground, power on, and confirm: the start button is read correctly (Section 8.1), the LIDAR reports plausible distances (Section 3.2), the camera opens and detects a held-up red or green object (Section 4.2), and the Pico 2 responds to a centered/neutral `PicoCommand` without the motor spinning unexpectedly.

### 10. First driving test.

Set the robot down on an open mat, start the program, and confirm the reactive controller (Section 4.3) holds a roughly straight line and reacts sensibly as a wall is brought closer on one side. This is the same manual bench test that led to the tuning work in Section 7.

[Back to Top](#kmids-veloz)

---

## 12. Development Process and Future Improvements

### 12.1 Mechanical and Software Iteration History

**Chassis iteration.** The chassis went through three major revisions during development. **Chassis V1** was our initial design and established the basic layout of the drivetrain, electronics, and sensor mounts.

Chassis V1

*Chassis V1*

**Chassis V2** repositioned the LIDAR in front of the Raspberry Pi 5 so that the Pi would no longer obstruct the LIDAR's field of view. This revision also compressed the chassis layout slightly to reduce unnecessary space.

Chassis V2

*Chassis V2*

The assembly files currently use this file. However, there is little to no difference between versions 2 and 3 apart from the length of the chassis instead. Thus, it is completely possible to follow the assembly instructions in Section 11 with Chassis V3.

**Chassis V3**, the current revision, shortened the overall chassis by approximately 35 mm. This reduced dead space and improved maneuverability by making the robot more compact.

Chassis V3

*Chassis V3*

**Hardware selection pass (mechanical).** Before settling on the S0009M servo and RPLidar S3, we evaluated the alternatives compared side by side in Section 2.1, Section 2.2, and Section 3.2. Including a mid-season LIDAR swap after our original unit's range and resolution proved hard to work with reliably. The current Ackermann linkage (Section 2.2) is on its first built revision.

**Control software rewrite.** The season started with `open_challenge.cpp`'s approach: a held IMU heading target, a proportional wall-offset correction against a 300mm outer-wall setpoint, and an explicit five-state machine (`NORMAL`/`PRE_TURN`/`TURNING`/`PRE_STOP`/`STOP`) for lap and turn counting (Section 5.1). Tuning this combination was difficult because the heading-hold term and the turn-detection state machine could disagree about robot behavior near a corner, one reasoning about absolute heading, the other about instantaneous front-wall distance. We moved to the simpler reactive scheme now active in `navigation.cpp` (Section 4.3) to remove that source of disagreement: a single, smaller set of directly-physical constants (deadband, reaction distance, max steering step) proved faster to tune by hand than the two-loop system it replaced. The `open_challenge.cpp` module remains in the repository as documented, maintained code (Section 6) rather than being deleted.

**Reactive controller tuning (measured, see Section 7).** The deadband/rate-limit fix described in Section 7.1: oversteering and wall contact on straights (problem) → added `SIDE_DEADBAND_MM` and `MAX_STEERING_STEP_DEG` (change) → wall-contact events dropped from an average of 4.4 to 0.6 per run across our 5-session sample (result).

### 12.2 Planned Improvements

Ordered by priority:

1. **Camera → navigation pillar-pass integration (Section 5.2).** Detection, steering-bias integration, and sensor arbitration are implemented; current validation (92.5% pillar-pass, Section 7.1) is from practice-mat testing, so broader on-track validation across more layouts is the remaining step.
2. **Parallel-parking sequence (Section 5.3).** The four-state reverse-park FSM is implemented and tuned; current success rate is 70% (Section 7.1), with alignment-phase consistency as the main area for further tuning.
3. **Add the Pico 2 firmware source to this repository** (Section 8.2, Section 8.3) for full reproducibility.
4. **Decide on `open_challenge.cpp` reactivation** alongside or instead of the reactive controller (Section 5.1, Section 6).
5. **Resolve the `PicoTelemetry` struct-packing assumption** with explicit fixed-layout serialization (Section 3.4).
6. **Export remaining STL files and finish `.3mf` slicer profiles** for all parts (Section 10.2, 10.3).
7. **Add remaining photos and videos** — the Open and Obstacle Challenge demonstration videos (Section 1.2, 1.3).
8. **Lock camera exposure and white balance** against actual competition-venue lighting (Section 3.2).

[Back to Top](#kmids-veloz)

---

## 13. License

This repository is distributed under the MIT License.

---

**KMIDS Veloz • WRO Future Engineers 2026**

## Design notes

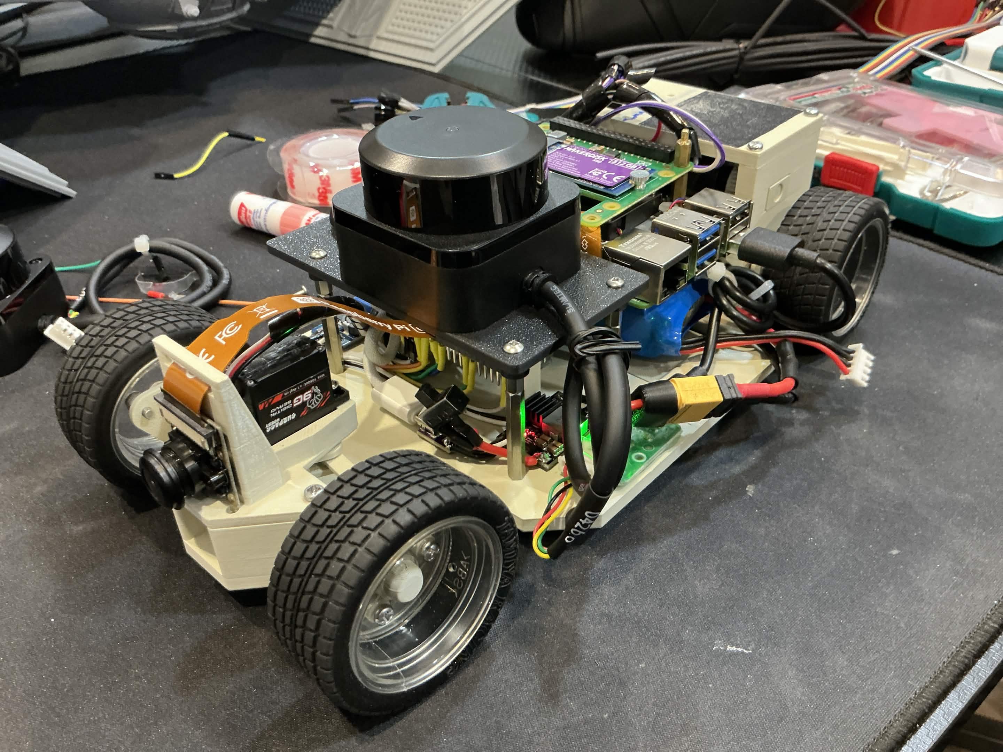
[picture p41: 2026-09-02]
assets/robot_views/chassisv2.jpg

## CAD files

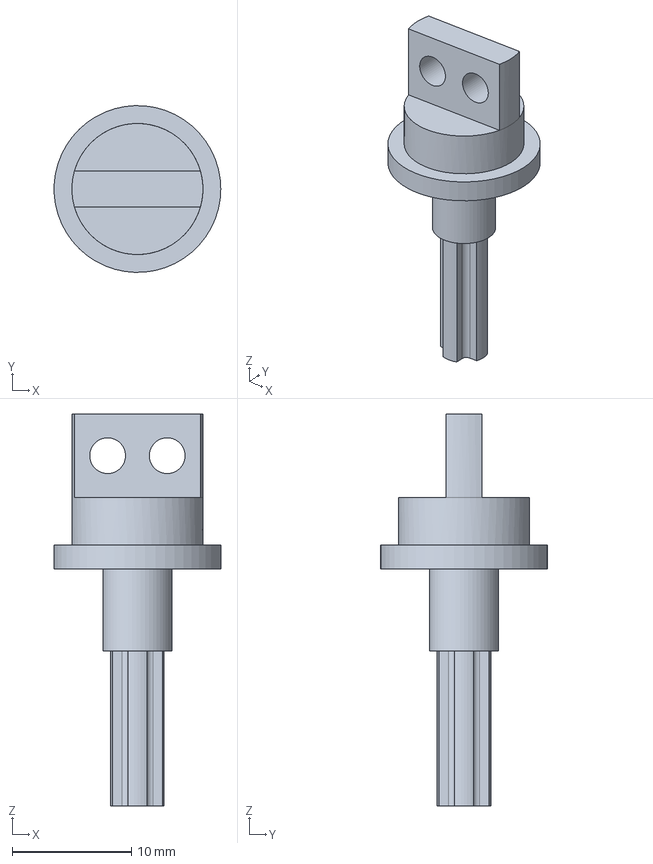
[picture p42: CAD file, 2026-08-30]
FreeCAD-Files/Parts/BackWheelAxle/BackWheelAxleLeft.FCStd
14.0 x 14.0 x 32.9 mm

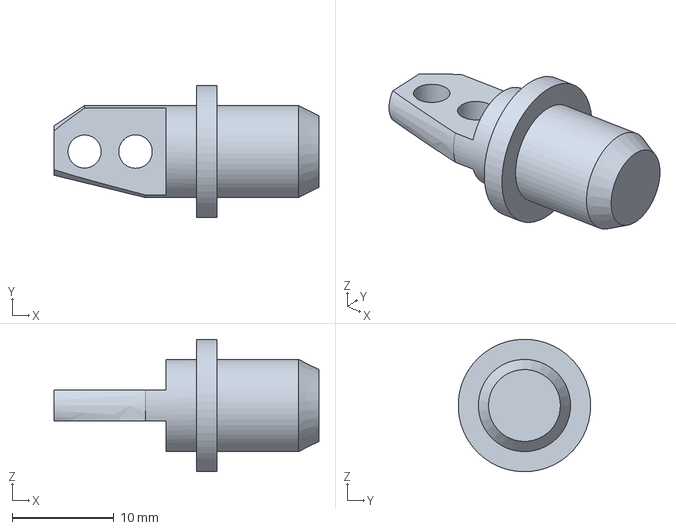
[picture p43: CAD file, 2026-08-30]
FreeCAD-Files/Parts/FrontWheelAxle/FrontWheelAxleRight.FCStd
26.0 x 13.0 x 13.0 mm

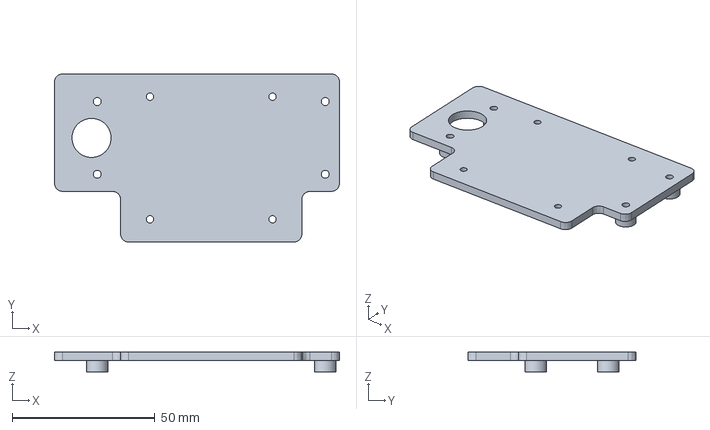
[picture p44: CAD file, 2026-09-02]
FreeCAD-Files/Parts/LidarPlateFinal.FCStd
100.0 x 59.0 x 7.00 mm

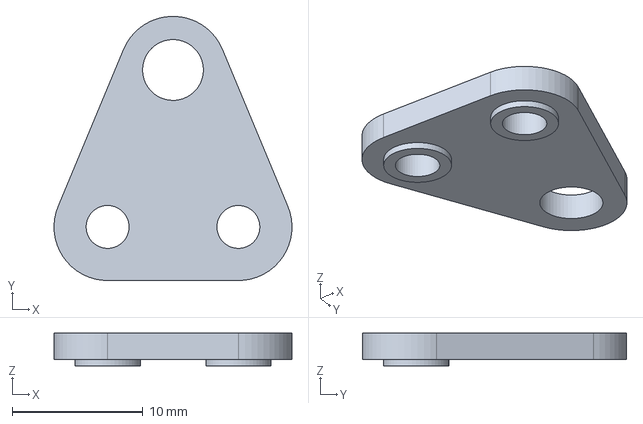
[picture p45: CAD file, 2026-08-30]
FreeCAD-Files/Parts/TBoneLinkage/TBoneLinkageTop.FCStd
18.2 x 20.2 x 2.50 mm

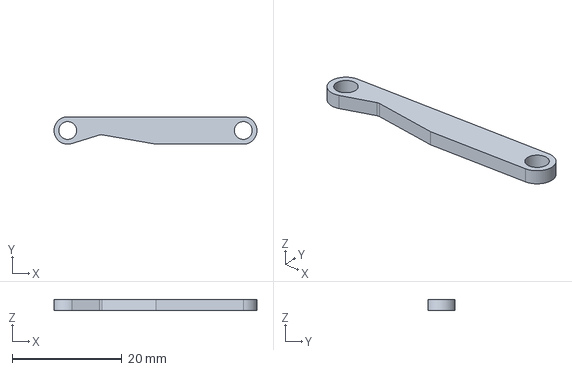
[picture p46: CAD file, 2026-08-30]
FreeCAD-Files/Parts/TransferLinkage/TransferLinkageLeft.FCStd
37.0 x 5.00 x 2.00 mm

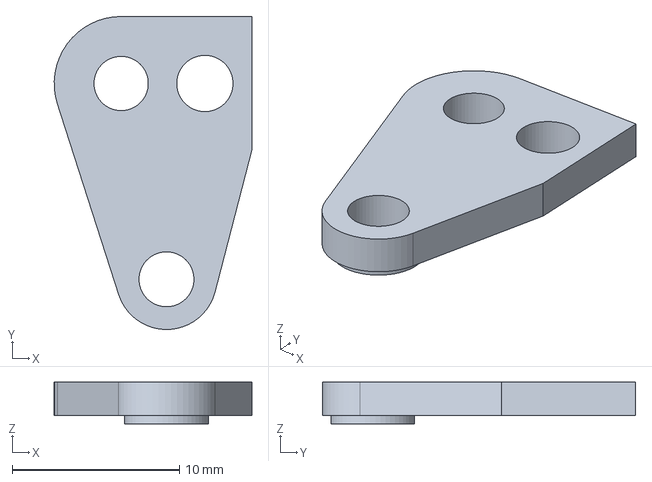
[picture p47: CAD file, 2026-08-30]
FreeCAD-Files/Parts/WheelLinkage/WheelLinkageTopRight.FCStd
11.8 x 18.7 x 2.50 mm

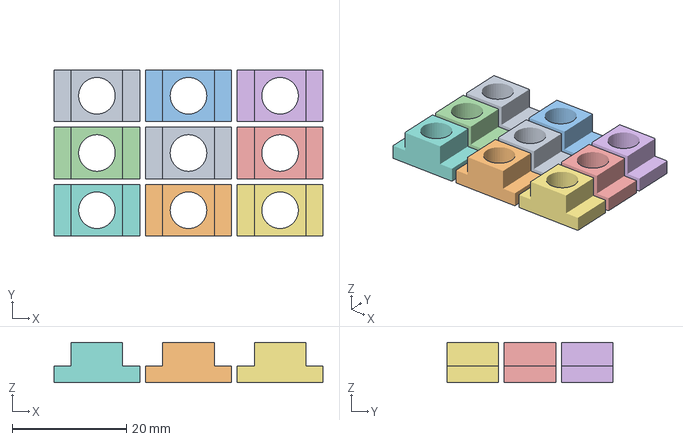
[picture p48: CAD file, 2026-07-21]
Slicer-Files/AxleHolder.3mf
47.0 x 29.0 x 7.00 mm
AxleHolder-AxleHolderPart.stl x 9

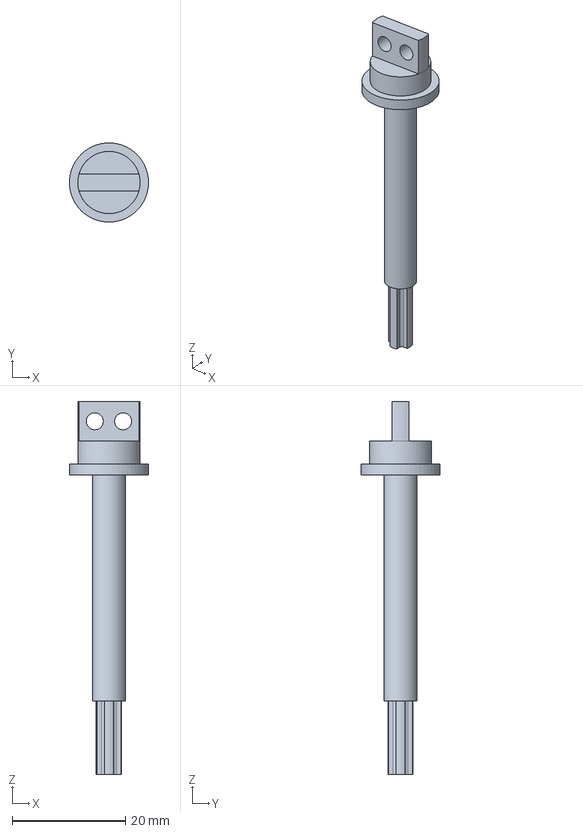
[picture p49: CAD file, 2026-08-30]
FreeCAD-Files/Parts/BackWheelAxle/BackWheelAxleRight.FCStd
14.0 x 14.0 x 65.9 mm

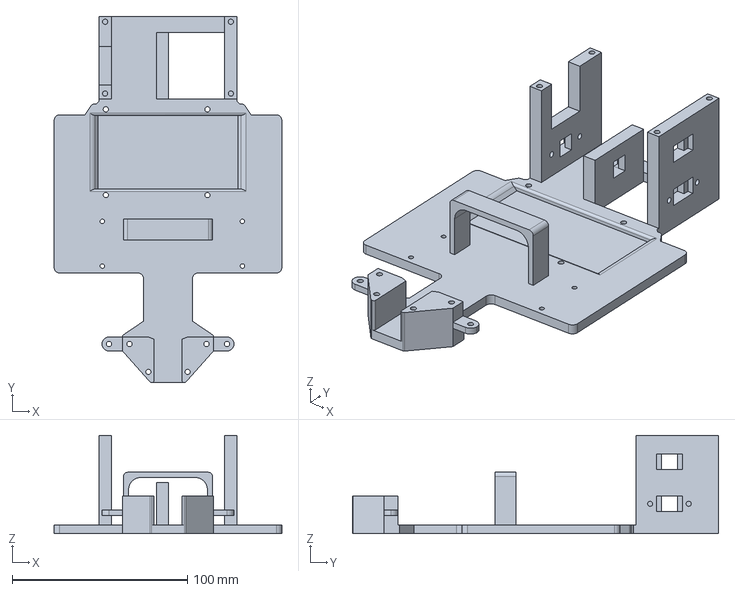
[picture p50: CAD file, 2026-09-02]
FreeCAD-Files/Parts/ChassisFinal.FCStd
130.0 x 209.0 x 56.0 mm

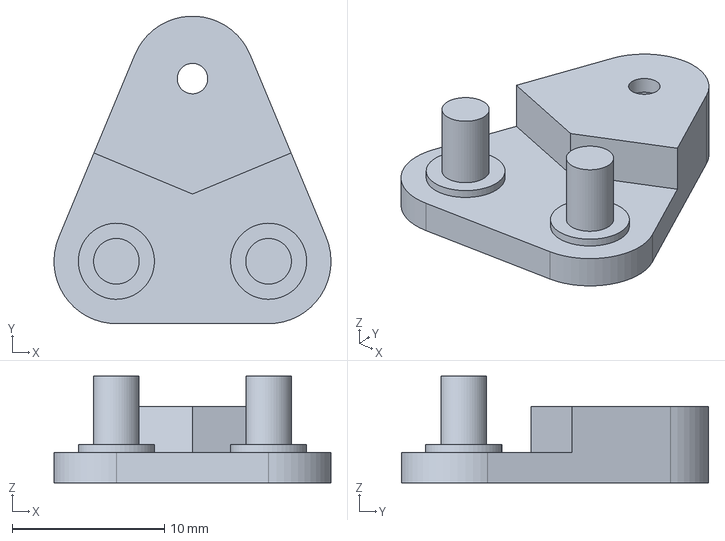
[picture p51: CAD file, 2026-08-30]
FreeCAD-Files/Parts/TBoneLinkage/TBoneLinkageBottom.FCStd
18.2 x 20.2 x 7.00 mm

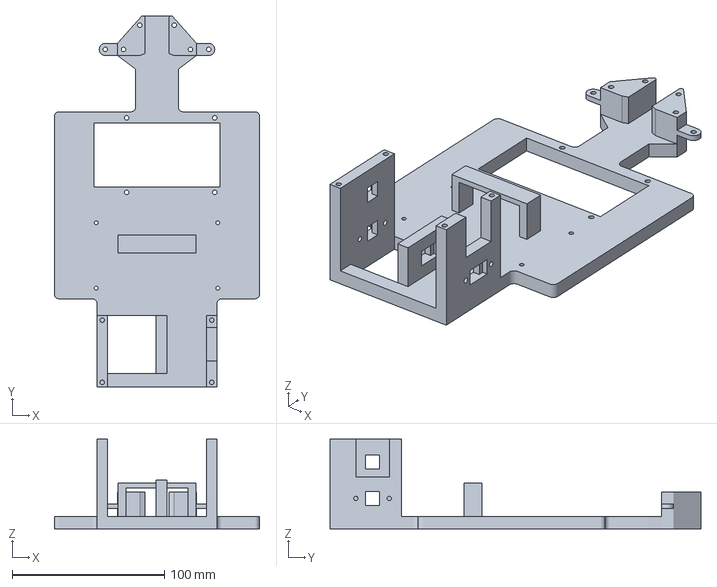
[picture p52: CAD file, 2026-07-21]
Slicer-Files/Chassis.3mf
135.0 x 244.0 x 59.0 mm

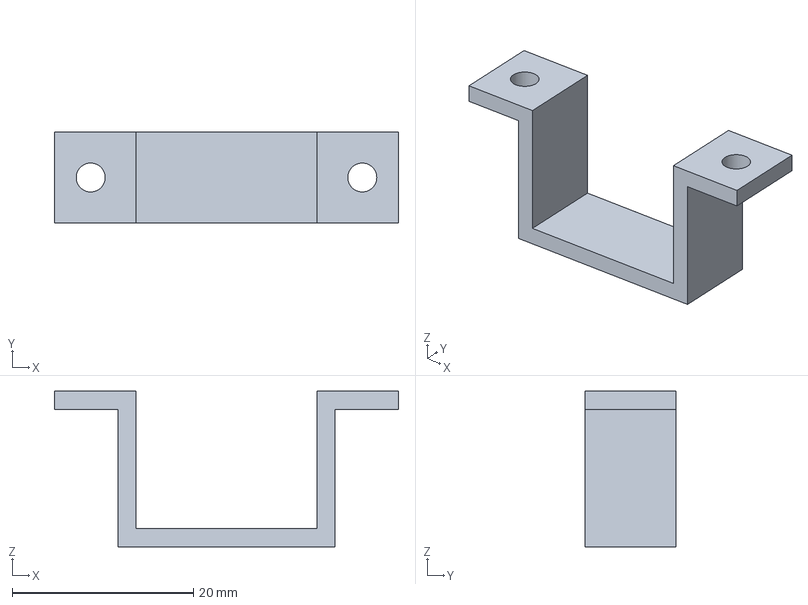
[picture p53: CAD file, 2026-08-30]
FreeCAD-Files/Parts/MotorHolder.FCStd
38.0 x 10.0 x 17.2 mm

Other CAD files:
FreeCAD-Files/Assemblies/Main Assembly.FCStd
FreeCAD-Files/Assemblies/Front Assembly.FCStd
FreeCAD-Files/Models/SteeringAckermannModel.FCStd
FreeCAD-Files/Parts/FrontWheelAxle/FrontWheelAxleLeft.FCStd
FreeCAD-Files/Parts/TransferLinkage/TransferLinkageRight.FCStd
FreeCAD-Files/Parts/WheelLinkage/WheelLinkageTopLeft.FCStd
FreeCAD-Files/Parts/16GA.FCStd
FreeCAD-Files/Parts/20GP-180 DC.FCStd
FreeCAD-Files/Parts/AxleHolder.FCStd
FreeCAD-Files/Parts/BackWheelConnector.FCStd
FreeCAD-Files/Parts/BackWheelStopper.FCStd
FreeCAD-Files/Parts/Chassis.FCStd
FreeCAD-Files/Parts/FrontCover.FCStd
FreeCAD-Files/Parts/FrontWheelStopper.FCStd
FreeCAD-Files/Parts/LegoBevelGear.FCStd
FreeCAD-Files/Parts/LegoDifferentialGear.FCStd
FreeCAD-Files/Parts/LidarPlate.FCStd
FreeCAD-Files/Parts/MotorGear.FCStd
FreeCAD-Files/Parts/MotorPlate.FCStd
FreeCAD-Files/Parts/RPLidarC1.FCStd
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

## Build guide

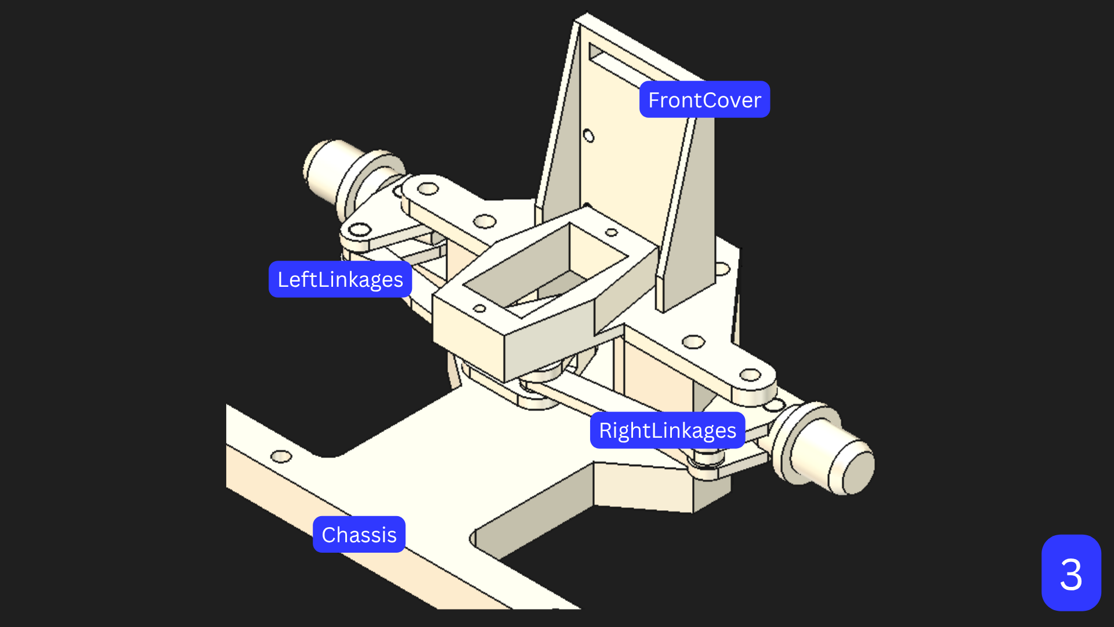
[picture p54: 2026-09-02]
assets/assembly/front_assembly/Front Assembly Step 3 Complete.png

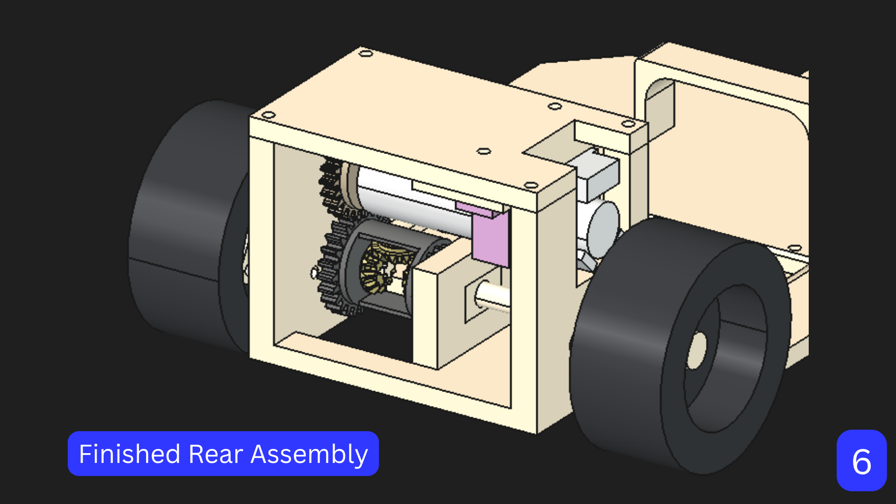
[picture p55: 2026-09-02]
assets/assembly/rear_assembly/Finished Rear Assembly.png

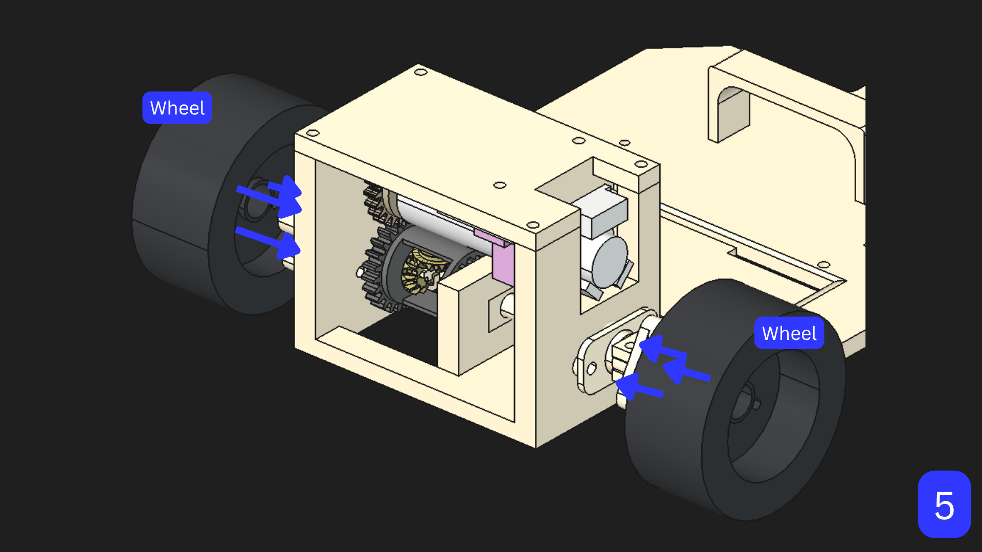
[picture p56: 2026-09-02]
assets/assembly/rear_assembly/Rear Assembly Step 5.png

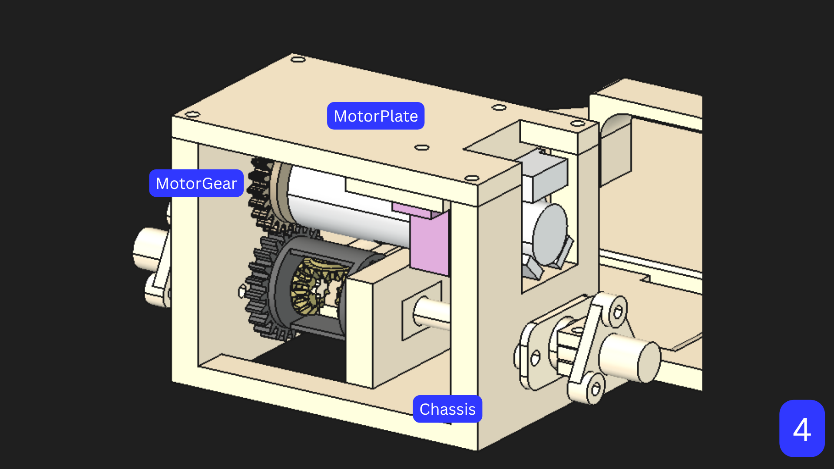
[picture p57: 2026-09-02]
assets/assembly/rear_assembly/Rear Assembly Step 4 Complete.png

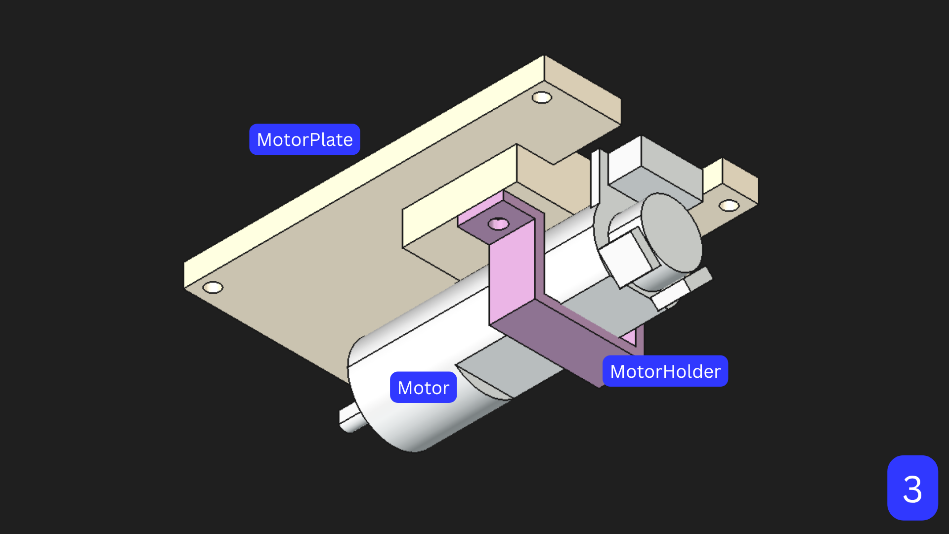
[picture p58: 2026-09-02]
assets/assembly/rear_assembly/Rear Assembly Step 3 Complete.png

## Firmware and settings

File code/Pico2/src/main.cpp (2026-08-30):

#include <stdio.h>
#include <stdint.h>

#include "pico/stdlib.h"

#include "config.h"
#include "encoder.h"
#include "imu.h"
#include "motor.h"
#include "pi_i2c.h"
#include "servo.h"

// ==========================================================
// VELOZ PICO 2 CONTROLLER
//
// Raspberry Pi 5 = MASTER / BRAIN
// Pico 2         = I2C SLAVE / HARDWARE CONTROLLER
//
// Raspberry Pi decides:
//     - motor speed
//     - steering angle
//
// Pico executes:
//     - motor
//     - servo
//     - encoder
//     - IMU
//
// If Pi communication disappears:
//     - MOTOR STOP
//     - SERVO CENTER
// ==========================================================


// ==========================================================
// SAFETY
// ==========================================================

constexpr uint32_t COMMAND_TIMEOUT_MS = 300;


// ==========================================================
// LOOP TIMING
// ==========================================================

// Main controller loop
constexpr uint32_t MAIN_LOOP_MS = 1;

// Telemetry update
constexpr uint32_t TELEMETRY_INTERVAL_MS = 20;

// Debug printing
constexpr uint32_t DEBUG_INTERVAL_MS = 500;


// ==========================================================
// STEERING
// ==========================================================

constexpr int STEERING_MIN = 40;
constexpr int STEERING_CENTER = 90;
constexpr int STEERING_MAX = 140;


// ==========================================================
// STATE
// ==========================================================

uint32_t last_command_time_ms = 0;
uint32_t last_telemetry_time_ms = 0;
uint32_t last_debug_time_ms = 0;

bool watchdog_active = true;

// Last actual hardware command
int last_speed = 0;
int last_steering = STEERING_CENTER;


// ==========================================================
// HELPERS
// ==========================================================

int clamp_steering(int angle)
{
    if (angle < STEERING_MIN)
    {
        return STEERING_MIN;
    }

    if (angle > STEERING_MAX)
    {
        return STEERING_MAX;
    }

    return angle;
}


// ==========================================================
// MOTOR COMMAND
// ==========================================================

void apply_motor_command(int speed)
{
    // Don't keep rewriting the same motor PWM.
    if (speed == last_speed)
    {
        return;
    }

    if (speed > 0)
    {
        motor_forward(
            static_cast<float>(
                speed
            )
        );
    }
    else if (speed < 0)
    {
        motor_reverse(
            static_cast<float>(
                -speed
            )
        );
    }
    else
    {
        motor_stop();
    }

    last_speed = speed;
}


// ==========================================================
// SERVO COMMAND
// ==========================================================

void apply_servo_command(int steering)
{
    steering =
        clamp_steering(
            steering
        );

    // Don't rewrite identical servo position.
    if (steering == last_steering)
    {
        return;
    }

    servo_write(
        steering
    );

    last_steering = steering;
}


// ==========================================================
// FORCE SAFE STATE
// ==========================================================

void force_safe_state()
{
    // Always physically issue the stop.
    // Do NOT rely only on software state.

    motor_stop();

    servo_center();

    last_speed = 0;
    last_steering = STEERING_CENTER;
}


// ==========================================================
// MAIN
// ==========================================================

int main()
{
    // ======================================================
    // SERIAL
    // ======================================================

    stdio_init_all();

    sleep_ms(1500);

    printf("\n");
    printf("====================================\n");
    printf("VELOZ PICO 2\n");
    printf("I2C SLAVE CONTROLLER\n");
    printf("RASPBERRY PI 5 = MASTER\n");
    printf("====================================\n");


    // ======================================================
    // MOTOR
    // ======================================================

    printf("[1] Motor init...\n");

    motor_init();

    motor_stop();

    printf("[1] Motor ready - STOPPED\n");


    // ======================================================
    // SERVO
    // ======================================================

    printf("[2] Servo init...\n");

    servo_init();

    servo_center();

    printf("[2] Servo ready - CENTER\n");


    // ======================================================
    // ENCODER
    // ======================================================

    printf("[3] Encoder init...\n");

    encoder_init();

    printf("[3] Encoder ready\n");


    // ======================================================
    // IMU
    // ======================================================

    printf("[4] IMU init...\n");

    bool imu_ready =
        imu_init();

    if (imu_ready)
    {
        printf("[4] IMU ready\n");
    }
    else
    {
        printf(
            "[4] IMU unavailable\n"
        );

        printf(
            "[4] Continuing without IMU control\n"
        );
    }


    // ======================================================
    // PI I2C
    // ======================================================

    printf("[5] Pi I2C slave init...\n");

    pi_i2c_init();

    printf(
        "[5] I2C slave ready at 0x39\n"
    );


    // ======================================================
    // INITIAL SAFE STATE
    // ======================================================

    force_safe_state();

    const uint32_t start_time =
        to_ms_since_boot(
            get_absolute_time()
        );

    last_command_time_ms =
        start_time;

    last_telemetry_time_ms =
        start_time;

    last_debug_time_ms =
        start_time;

    watchdog_active = true;


    // ======================================================
    // READY
    // ======================================================

    printf("\n");
    printf("====================================\n");
    printf("PICO READY\n");
    printf("Waiting for Raspberry Pi commands\n");
    printf(
        "WATCHDOG: %u ms\n",
        COMMAND_TIMEOUT_MS
    );
    printf(
        "STEERING: %d / %d / %d\n",
        STEERING_MIN,
        STEERING_CENTER,
        STEERING_MAX
    );
    printf("====================================\n");


    // ======================================================
    // MAIN LOOP
    // ======================================================

    while (true)
    {
        const uint32_t now_ms =
            to_ms_since_boot(
                get_absolute_time()
            );


        // ==================================================
        // SENSOR UPDATE
        // ==================================================

        encoder_update();

        bool imu_updated = false;

        if (imu_ready)
        {
            imu_updated =
                imu_update();
        }


        // ==================================================
        // RECEIVE COMMAND FROM RASPBERRY PI
        // ==================================================

        if (
            pi_i2c_command_received()
        )
        {
            const PiCommand command =
                pi_i2c_get_command();


            // ----------------------------------------------
            // Clear command flag immediately after copying.
            // ----------------------------------------------

            pi_i2c_clear_command_flag();


            // ----------------------------------------------
            // Refresh watchdog
            // ----------------------------------------------

            last_command_time_ms =
                now_ms;

            if (watchdog_active)
            {
                watchdog_active =
                    false;

                printf(
                    "MASTER CONNECTED\n"
                );
            }


            // ==============================================
            // EMERGENCY STOP
            // ==============================================

            if (
                command.emergency_stop
            )
            {
                force_safe_state();

                printf(
                    "ESTOP -> MOTOR STOP\n"
                );
            }


            // ==============================================
            // NORMAL CONTROL
            // ==============================================

            else
            {
                // ------------------------------------------
                // SPEED
                // ------------------------------------------

                int speed =
                    static_cast<int>(
                        command.speed_percent
                    );

                if (speed > 100)
                {
                    speed = 100;
                }

                if (speed < -100)
                {
                    speed = -100;
                }


                // ------------------------------------------
                // STEERING
                // ------------------------------------------

                const int steering =
                    clamp_steering(
                        static_cast<int>(
                            command.steering_angle
                        )
                    );


                // ------------------------------------------
                // APPLY
                // ------------------------------------------

                apply_motor_command(
                    speed
                );

                apply_servo_command(
                    steering
                );
            }
        }


        // ==================================================
        // WATCHDOG
        // ==================================================

        const uint32_t command_age =
            now_ms -
            last_command_time_ms;

        if (
            command_age >
            COMMAND_TIMEOUT_MS
        )
        {
            // IMPORTANT:
            //
            // Force the hardware safe EVERY LOOP while
            // communication is missing.
            //
            // We do not trust cached software values.

            motor_stop();

            servo_center();

            last_speed = 0;
            last_steering =
                STEERING_CENTER;

            if (!watchdog_active)
            {
                watchdog_active =
                    true;

                printf(
                    "WATCHDOG TIMEOUT\n"
                );

                printf(
                    "MASTER LOST -> MOTOR STOP\n"
                );
            }
        }


        // ==================================================
        // TELEMETRY
        // ==================================================

        if (
            now_ms -
            last_telemetry_time_ms >=
            TELEMETRY_INTERVAL_MS
        )
        {
            last_telemetry_time_ms =
                now_ms;

            PicoTelemetry telemetry {};

            telemetry.encoder_count =
                encoder_get_count();

            telemetry.rpm_x10 =
                static_cast<int16_t>(
                    encoder_get_rpm()
                    * 10.0f
                );


            // ----------------------------------------------
            // IMU
            // ----------------------------------------------

            if (imu_ready)
            {
                telemetry.yaw_x10 =
                    static_cast<int16_t>(
                        imu_get_yaw_deg()
                        * 10.0f
                    );

                telemetry.pitch_x10 =
                    static_cast<int16_t>(
                        imu_get_pitch_deg()
                        * 10.0f
                    );

                telemetry.roll_x10 =
                    static_cast<int16_t>(
                        imu_get_roll_deg()
                        * 10.0f
                    );
            }
            else
            {
                telemetry.yaw_x10 = 0;
                telemetry.pitch_x10 = 0;
                telemetry.roll_x10 = 0;
            }


            pi_i2c_set_telemetry(
                telemetry
            );
        }


        // ==================================================
        // DEBUG
        // ==================================================

        if (
            now_ms -
            last_debug_time_ms >=
            DEBUG_INTERVAL_MS
        )
        {
            last_debug_time_ms =
                now_ms;

            printf(
                "PICO"
                " | Speed=%d"
                " | Steering=%d"
                " | RPM=%.1f"
                " | WD=%s"
                " | Age=%lu"
                " | IMU=%d\n",

                last_speed,

                last_steering,

                encoder_get_rpm(),

                watchdog_active
                    ? "STOP"
                    : "OK",

                static_cast<unsigned long>(
                    command_age
                ),

                imu_updated
                    ? 1
                    : 0
            );
        }


        // ==================================================
        // CONTROL LOOP TIMING
        // ==================================================

        tight_loop_contents();

        sleep_ms(
            MAIN_LOOP_MS
        );
    }


    return 0;
}

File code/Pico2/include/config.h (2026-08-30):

#pragma once
#include <cstdint>

// Servo
constexpr unsigned int SERVO_PIN = 15;

constexpr int SERVO_CENTER = 90;
constexpr int SERVO_LEFT = 60;
constexpr int SERVO_RIGHT = 120;

constexpr int SERVO_CENTER_OFFSET = -1;

constexpr unsigned int SERVO_MIN_PULSE_US = 500;
constexpr unsigned int SERVO_MAX_PULSE_US = 2500;

// Motor
constexpr unsigned int MOTOR_C1 = 6;
constexpr unsigned int MOTOR_C2 = 7;

// PWM
constexpr unsigned int MOTOR_PWM_TOP = 1000;
constexpr unsigned int MOTOR_PWM_FREQUENCY_HZ = 20000;

// Encoder
constexpr unsigned int ENCODER_A = 10;
constexpr unsigned int ENCODER_B = 11;

// Encoder settings
constexpr float ENCODER_COUNTS_PER_REVOLUTION = 600.0f;
constexpr unsigned int ENCODER_UPDATE_PERIOD_MS = 100;

// =====================================================
// BNO085 I2C0
// =====================================================

constexpr unsigned int IMU_SDA_PIN = 4;
constexpr unsigned int IMU_SCL_PIN = 5;

constexpr unsigned int IMU_I2C_BAUDRATE = 400000;

constexpr unsigned int BNO085_ADDRESS = 0x4A;

// =====================================================
// RASPBERRY PI 5 COMMUNICATION I2C1
// =====================================================

constexpr unsigned int PI_SDA_PIN = 2;
constexpr unsigned int PI_SCL_PIN = 3;

constexpr unsigned int PI_I2C_BAUDRATE = 400000;

// Pico slave address chosen for Pi communication
constexpr unsigned int PICO_I2C_ADDRESS = 0x39;

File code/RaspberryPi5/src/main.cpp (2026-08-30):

#include "lidar.h"
#include "openchallenge.h"
#include "obstaclechallenge.h"
#include "parking.h"
#include "pico_i2c.h"

#include <chrono>
#include <csignal>
#include <cstdint>
#include <iostream>
#include <thread>

// ==========================================================
// VELOZ
// WRO FUTURE ENGINEER
// ==========================================================

namespace
{

// ==========================================================
// PROGRAM MODE
// ==========================================================
//
// Change ONLY this line:
//
// OPEN_CHALLENGE
// OBSTACLE_CHALLENGE
// PARKING
//
// ==========================================================

enum class RobotMode
{
    OPEN_CHALLENGE,
    OBSTACLE_CHALLENGE,
    PARKING
};

constexpr RobotMode ROBOT_MODE =
    RobotMode::OPEN_CHALLENGE;

// ==========================================================
// GLOBAL STOP
// ==========================================================

volatile std::sig_atomic_t stop_requested = 0;

// ==========================================================
// SIGNAL HANDLER
// ==========================================================

void signal_handler(int)
{
    stop_requested = 1;

    // Tell every possible challenge loop to stop.
    open_challenge_stop();
    obstacle_challenge_stop();
    parking_stop();
}

// ==========================================================
// SAFE STOP
// ==========================================================

void send_stop()
{
    PicoCommand command{};

    command.speed_percent = 0;
    command.steering_angle = 90;
    command.emergency_stop = 1;

    pico_i2c_send_command(command);
}

// ==========================================================
// MODE NAME
// ==========================================================

const char* mode_name()
{
    switch (ROBOT_MODE)
    {
        case RobotMode::OPEN_CHALLENGE:
            return "OPEN CHALLENGE";

        case RobotMode::OBSTACLE_CHALLENGE:
            return "OBSTACLE CHALLENGE";

        case RobotMode::PARKING:
            return "PARKING";
    }

    return "UNKNOWN";
}

// ==========================================================
// START SELECTED MODE
// ==========================================================

void start_selected_mode()
{
    switch (ROBOT_MODE)
    {
        case RobotMode::OPEN_CHALLENGE:
        {
            open_challenge_start();
            break;
        }

        case RobotMode::OBSTACLE_CHALLENGE:
        {
            obstacle_challenge_start();
            break;
        }

        case RobotMode::PARKING:
        {
            parking_start();
            break;
        }
    }
}

} // namespace

// ==========================================================
// MAIN
// ==========================================================

int main()
{
    // ======================================================
    // SIGNALS
    // ======================================================

    std::signal(
        SIGINT,
        signal_handler
    );

    std::signal(
        SIGTERM,
        signal_handler
    );

    // ======================================================
    // STARTUP MESSAGE
    // ======================================================

    std::cout
        << "\n"
        << "====================================\n"
        << "VELOZ\n"
        << "WRO FUTURE ENGINEER\n"
        << "====================================\n"
        << "MODE: "
        << mode_name()
        << "\n"
        << "====================================\n"
        << std::endl;

    // ======================================================
    // 1. INITIALIZE PICO 2
    // ======================================================

    std::cout
        << "[1] Connecting to Pico 2..."
        << std::endl;

    if (!pico_i2c_init())
    {
        std::cerr
            << "ERROR: Pico 2 initialization failed."
            << std::endl;

        return 1;
    }

    // ======================================================
    // IMMEDIATE MOTOR STOP
    // ======================================================

    send_stop();

    std::this_thread::sleep_for(
        std::chrono::milliseconds(100)
    );

    std::cout
        << "[1] Pico ready"
        << std::endl;

    // ======================================================
    // 2. INITIALIZE RPLIDAR S3
    // ======================================================

    std::cout
        << "[2] Initializing RPLIDAR S3..."
        << std::endl;

    if (!lidar_init())
    {
        std::cerr
            << "ERROR: RPLIDAR S3 initialization failed."
            << std::endl;

        send_stop();

        return 1;
    }

    std::cout
        << "[2] RPLIDAR S3 ready"
        << std::endl;

    // ======================================================
    // 3. WAIT FOR REAL LIDAR DATA
    // ======================================================

    std::cout
        << "[3] Waiting for LiDAR data..."
        << std::endl;

    bool lidar_data_received = false;

    const auto lidar_wait_start =
        std::chrono::steady_clock::now();

    while (!stop_requested)
    {
        if (lidar_update())
        {
            const LidarDistances d =
                lidar_get_distances();

            // At least one important direction
            // must contain a valid measurement.
            if (
                d.front_mm > 0.0f ||
                d.left_mm  > 0.0f ||
                d.right_mm > 0.0f
            )
            {
                lidar_data_received = true;

                break;
            }
        }

        const auto now =
            std::chrono::steady_clock::now();

        const auto elapsed_ms =
            std::chrono::duration_cast<
                std::chrono::milliseconds
            >(
                now - lidar_wait_start
            ).count();

        // Don't wait forever.
        if (elapsed_ms > 5000)
        {
            break;
        }

        std::this_thread::sleep_for(
            std::chrono::milliseconds(20)
        );
    }

    // ======================================================
    // LIDAR STARTUP FAILURE
    // ======================================================

    if (!lidar_data_received)
    {
        std::cerr
            << "ERROR: No valid LiDAR data received."
            << std::endl;

        send_stop();

        lidar_close();

        return 1;
    }

    // ======================================================
    // SHOW INITIAL DISTANCES
    // ======================================================

    const LidarDistances initial =
        lidar_get_distances();

    std::cout
        << "[3] LiDAR data confirmed"
        << std::endl;

    std::cout
        << "    F="
        << initial.front_mm

        << " | L="
        << initial.left_mm

        << " | R="
        << initial.right_mm

        << " | B="
        << initial.back_mm

        << std::endl;
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

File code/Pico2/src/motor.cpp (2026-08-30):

#include "motor.h"

#include "config.h"

#include "hardware/clocks.h"
#include "hardware/pwm.h"
#include "pico/stdlib.h"

namespace
{
float clamp_percent(float speed_percent)
{
    if (speed_percent < 0.0f)
    {
        return 0.0f;
    }

    if (speed_percent > 100.0f)
    {
        return 100.0f;
    }

    return speed_percent;
}

uint16_t percent_to_pwm(float speed_percent)
{
    speed_percent = clamp_percent(speed_percent);

    return static_cast<uint16_t>(
        speed_percent *
        static_cast<float>(MOTOR_PWM_TOP - 1) /
        100.0f
    );
}
}

void motor_init()
{
    gpio_set_function(MOTOR_C1, GPIO_FUNC_PWM);
    gpio_set_function(MOTOR_C2, GPIO_FUNC_PWM);

    const uint slice = pwm_gpio_to_slice_num(MOTOR_C1);

    pwm_config config = pwm_get_default_config();

    const float divider =
        static_cast<float>(clock_get_hz(clk_sys)) /
        static_cast<float>(
            MOTOR_PWM_FREQUENCY_HZ * MOTOR_PWM_TOP
        );

    pwm_config_set_clkdiv(&config, divider);
    pwm_config_set_wrap(&config, MOTOR_PWM_TOP - 1);

    pwm_init(slice, &config, true);

    motor_stop();
}

void motor_forward(float speed_percent)
{
    const uint16_t pwm_level =
        percent_to_pwm(speed_percent);

    pwm_set_gpio_level(MOTOR_C1, pwm_level);
    pwm_set_gpio_level(MOTOR_C2, 0);
}

void motor_reverse(float speed_percent)
{
    const uint16_t pwm_level =
        percent_to_pwm(speed_percent);

    pwm_set_gpio_level(MOTOR_C1, 0);
    pwm_set_gpio_level(MOTOR_C2, pwm_level);
}

void motor_stop()
{
    // Both LOW means coast.
    pwm_set_gpio_level(MOTOR_C1, 0);
    pwm_set_gpio_level(MOTOR_C2, 0);
}

void motor_brake()
{
    // Both HIGH means active brake.
    pwm_set_gpio_level(MOTOR_C1, MOTOR_PWM_TOP - 1);
    pwm_set_gpio_level(MOTOR_C2, MOTOR_PWM_TOP - 1);
}

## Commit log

2026-06-14 feat: Add SteeringModel
    [SteeringAckermannModel.FCStd]
2026-07-21 feat: Add Chassis plate
    [Chassis.FCStd, SteeringAckermannModel.FCStd]
2026-07-21 feat: Add front bridge to the chassis
    [Chassis.FCStd]
2026-07-21 feat: Add 16GA
    [16GA.FCStd]
2026-07-21 feat: Add motor and differential holder to the Chassis
    [Chassis.FCStd]
2026-07-21 feat: Finish Chassis
    [Chassis.FCStd]
2026-07-21 feat: Add MotorPlate
    [Chassis.FCStd, MotorPlate.FCStd]
2026-07-21 feat: Add MotorHolder
    [MotorHolder.FCStd]
2026-07-21 feat: Add FrontCover
    [FrontCover.FCStd]
2026-07-21 feat: Add TBoneLinkage
    [TBoneLinkageBottom.FCStd, TBoneLinkageTop.FCStd]
2026-07-21 feat: Add TransferLinkage
    [TransferLinkageLeft.FCStd, TransferLinkageRight.FCStd]
2026-07-21 feat: Add WheelLinkage
    [WheelLinkageBottomLeft.FCStd, WheelLinkageBottomRight.FCStd, WheelLinkageTopLeft.FCStd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]
2026-07-21 feat: Add FrontWheelAxle
    [FrontWheelAxleLeft.FCStd, FrontWheelAxleRight.FCStd]
2026-07-21 feat: Add FrontWheelStopper
    [FrontWheelStopper.FCStd]
2026-07-21 feat: Add AxleHolder
    [AxleHolder.FCStd]
2026-07-21 feat: Add BackWheelAxle
    [BackWheelAxleLeft.FCStd, BackWheelAxleRight.FCStd]
2026-07-21 feat: Add BackWheelConnector
    [BackWheelConnector.FCStd]
2026-07-21 feat: Add BackWheelStopper
    [BackWheelStopper.FCStd]
2026-07-21 feat: Add Wheel
    [Wheel.FCStd]
2026-07-21 feat: Add S0004m servo
    [S0004m.FCStd]
2026-07-21 feat: Import Lego gears
    [LegoBevelGear.FCStd, LegoDifferentialGear.FCStd]
2026-07-21 feat: Import RaspberryPi 5
    [RaspberryPi5.FCStd, RaspberryPi5M2Hat.FCStd]
2026-07-21 feat: Import RpiCamera
    [RpiCamera.FCStd]
2026-07-21 feat: Import RPLidarC1
    [RPLidarC1.FCStd]
2026-07-21 fix: Change Chassis holes for pi to fit
    [Chassis.FCStd, MotorPlate.FCStd]
2026-07-21 feat: Slice the CAD models
    [AxleHolder.3mf, BackWheelAxleBoth.3mf, Chassis.3mf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]
2026-07-21 feat: Add MotorGear
    [MotorGear.FCStd]
2026-07-21 feat: Slice MotorGear
    [MotorGear.3mf]
2026-07-21 fix: Change tolerance
    [AxleHolder.FCStd, FrontWheelAxleLeft.FCStd, FrontWheelAxleRight.FCStd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]
2026-07-21 fix: Fix gear size mismatch
    [MotorGear.3mf, MotorGear.FCStd]
2026-07-21 fix: Change AxleHolder tolerance
    [AxleHolder.FCStd]
2026-07-21 fix: Change Chassis tolerance
    [Chassis.FCStd]
2026-07-21 fix: Re-slice CAD models
    [AxleHolder.3mf, BackWheelAxleBoth.3mf, Chassis.3mf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]
2026-07-24 feat: Add LidarPlate
    [LidarPlate.FCStd]
2026-08-15 docs: added some power information
2026-08-16 docs: added i2c master slave diagram (minor)
2026-08-16 Update FreeCAD assembly
    [Chassis.FCStd, Front Assembly.FCStd, FrontCover.FCStd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]
2026-08-21 docs: updated images due to new lidar
2026-08-22 docs: update camera exposure status and remove UPS confirmation note
2026-08-22 docs: removed a couple TODO's complete and changed the planned improvements
2026-08-24 Updated assembly with rear motor components
    [16GA.FCStd, 20GP-180 DC.FCStd, AxleHolder.FCStd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]
2026-08-27 docs: [95%] edited relevant information and documented lidar change
2026-08-27 docs: fixed some old images to match lidar change from the 2 to the 3 and uploaded cad assembly
2026-08-31 Update main assembly
    [Main Assembly.FCStd]
2026-08-31 Add CAD assembly pictures
2026-09-01 Modify assembly instructions
2026-09-01 Finish front assembly instructions and polish
2026-09-01 Fix front assembly instructions
2026-09-01 Add rear drivetrain assembly instructions
2026-09-01 Add electronics mounting information
2026-09-01 Edit pico 2 information
2026-09-01 Fix assembly instructions test
2026-09-01 Fix assembly image bug
2026-09-02 Add comments on servo
2026-09-02 Add sources for servo selection
2026-09-02 Add chassis specifications
2026-09-02 Add power source info
2026-09-02 Update lidar consideration table
2026-09-02 Change power consumption data
2026-09-02 Change Pico 2 firmware info
2026-09-02 Add chassis version images
2026-09-02 Add chassis reiteration process to 12.1
2026-09-02 Add chassis version disclaimer
2026-09-02 Added chassis, lidarplate v3
    [ChassisFinal.FCStd, LidarPlateFinal.FCStd]
